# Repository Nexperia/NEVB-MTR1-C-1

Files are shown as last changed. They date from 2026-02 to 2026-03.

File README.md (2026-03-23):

<picture align="center">
  <source media="(prefers-color-scheme: dark)" srcset="https://raw.githubusercontent.com/Nexperia/NEVB-MTR1-C-1/refs/heads/main/images/nexperia_logo_white.svg">
  Nexperia Logo
</picture>

-----------------
# NEVB-MTR1-C-1: Motor Controller Board Hardware Design Files

 

## Introduction

This repository contains the hardware design files for the NEVB-MTR1-C-1 Motor Controller Board, a key component of Nexperia's Motor Evaluation Kit NEVB-MTR1-KIT1. The controller board serves as the central unit for motor control operations, interfacing between the microcontroller (Arduino Leonardo) and the 3-Phase Inverter Board.

The NEVB-MTR1-KIT1 evaluation kit includes:

- **Motor Controller Board (NEVB-MTR1-C-1)**: The central unit for motor control operations (this repository).
- **3-Phase Inverter Board (NEVB-MTR1-I56-1)**: The main powerstage for driving the motor.
- **Leonardo R3 Development Board**: Acts as the core microcontroller platform for the system.
- **3-Phase BLDC Motor with Hall Sensors**: The motor that is directly controlled by the system.
- Additional screws, plugs, and tools necessary for setup and operation.

## Board View

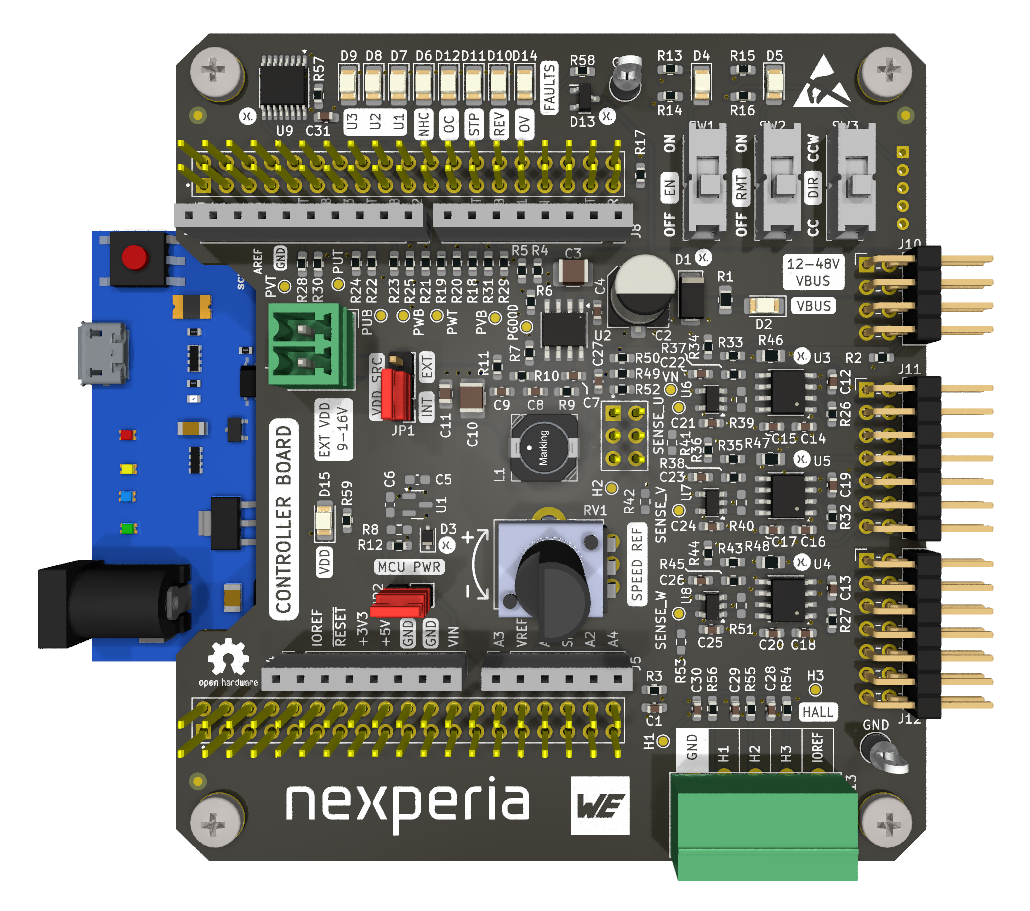
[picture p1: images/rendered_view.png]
Board Render


## Bill of Materials

An interactive Bill of Materials (iBOM) is available online at [https://nexperia.github.io/NEVB-MTR1-C-1/ibom.html](https://nexperia.github.io/NEVB-MTR1-C-1/ibom.html) or locally in the `bom/` directory (`bom/ibom.html`). The iBOM provides an interactive view of component placement, reference designators, and sourcing information. The BOM is also available in CSV format at `bom/nevb_mtr1_c_1.csv`.

## Manufacturing Files

Gerber files for PCB manufacturing are located in the `gerbers/` directory.

## Design Software

This board was designed using [KiCad](https://www.kicad.org/) EDA software (version 9.0 or newer recommended).

To open and edit the design:

1. Install KiCad from [https://www.kicad.org/download/](https://www.kicad.org/download/)
2. Open the project file: `nevb_mtr1_c_1.kicad_pro`

## Related Repositories

- **Firmware**: [NEVC-MTR1-t01](https://github.com/Nexperia/NEVC-MTR1-t01) - Trapezoidal control firmware for the evaluation kit
- **3-Phase Inverter Board Hardware Design Files**: [NEVB-MTR1-I56-1](https://github.com/Nexperia/https://github.com/Nexperia/NEVB-MTR1-I56-1) - Design files for the 3-phase inverter board

## Safety Precautions

When working with these hardware designs, exercise caution with high-voltage components and follow proper ESD, assembly, and testing procedures.

## Contributing

Contributions to improve the hardware design are welcome. To contribute:

- Fork the repository.
- Create a new branch for your feature or fix.
- Commit your changes with clear documentation.
- Push to your branch and submit a pull request.

## License

This project is licensed under the MIT/X Consortium License, a permissive free software license. For more details on the MIT/X Consortium License, please refer to the LICENSE file included in this repository.

## Schematics

The controller board design is organized into hierarchical schematic sheets:

Main Schematic

DC-DC Converter

Microcontroller

User Inputs

Gate Drivers

Back EMF Sense

Fault Reporting

Hardware and Notes

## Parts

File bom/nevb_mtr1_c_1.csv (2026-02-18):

Reference | Value | Datasheet | Footprint | Qty | DNP | Manufacturer | Mfg Part No | Mouser Part No | Farnell Part No | RS Part No
C1 | 22p-10V | https://www.we-online.com/components/products/datasheet/885012006004.pdf | Capacitor_SMD:C_0603_1608Metric_Pad1.08x0.95mm_HandSolder | 1 |  | WURTH ELEKTRONIK | 885012006004 | 710-885012006004 | 2533823 | ~
C2 | 10u-100V | https://www.we-online.com/components/products/datasheet/865060845002.pdf | Capacitor_SMD:CP_Elec_6.3x9.9 | 1 |  | WURTH ELEKTRONIK | 865060845002 | 710-865060845002 | 4061463 | ~
C3 | 2.2u-100V | https://www.we-online.com/components/products/datasheet/885012209071.pdf | Capacitor_SMD:C_1210_3225Metric_Pad1.33x2.70mm_HandSolder | 1 |  | WURTH ELEKTRONIK | 885012209071 | 710-885012209071 | 4061686 | ~
C4 | 0.1u-100V | https://www.we-online.com/components/products/datasheet/885012206120.pdf | Capacitor_SMD:C_0603_1608Metric_Pad1.08x0.95mm_HandSolder | 1 |  | WURTH ELEKTRONIK | 885012206120 | 710-885012206120 | 4061680 | ~
C5 | 1u-25V | https://www.we-online.com/components/products/datasheet/885012206076.pdf | Capacitor_SMD:C_0603_1608Metric_Pad1.08x0.95mm_HandSolder | 1 | DNP | WURTH ELEKTRONIK | 885012206076 | 710-885012206076 | 4261502 | ~
C6 | 1u-10V | https://www.we-online.com/components/products/datasheet/885012206026.pdf | Capacitor_SMD:C_0603_1608Metric_Pad1.08x0.95mm_HandSolder | 1 | DNP | WURTH ELEKTRONIK | 885012206026 | 710-885012206026 | 2534018 | ~
C7 | 2.2n-25V | https://www.we-online.com/components/products/datasheet/885012206061.pdf | Capacitor_SMD:C_0603_1608Metric_Pad1.08x0.95mm_HandSolder | 1 |  | WURTH ELEKTRONIK | 885012206061 | 710-885012206061 | 2534028 | ~
C8 | 47p | https://www.we-online.com/components/products/datasheet/885012006036.pdf | Capacitor_SMD:C_0603_1608Metric_Pad1.08x0.95mm_HandSolder | 1 |  | WURTH ELEKTRONIK | 885012006036 | 710-885012006036 | 2533837 | ~
C9 | 3.3n | https://www.we-online.com/components/products/datasheet/885012206062.pdf | Capacitor_SMD:C_0603_1608Metric_Pad1.08x0.95mm_HandSolder | 1 |  | WURTH ELEKTRONIK | 885012206062 | 710-885012206062 | 2534029 | ~
C10 | 47u-16V | https://www.we-online.com/components/products/datasheet/885012109011.pdf | Capacitor_SMD:C_1210_3225Metric_Pad1.33x2.70mm_HandSolder | 1 |  | WURTH ELEKTRONIK | 885012109011 | 710-885012109011 | 4261498 | ~
C11 | 1u-16V | https://www.we-online.com/components/products/datasheet/885012207051.pdf | Capacitor_SMD:C_0805_2012Metric_Pad1.18x1.45mm_HandSolder | 1 |  | WURTH ELEKTRONIK | 885012207051 | 710-885012207051 | 2534058 | ~
C12,C13,C19 | 220n-25V | https://www.we-online.com/components/products/datasheet/885012206073.pdf | Capacitor_SMD:C_0603_1608Metric_Pad1.08x0.95mm_HandSolder | 3 |  | WURTH ELEKTRONIK | 885012206073 | 710-885012206073 | 2495174 | ~
C14,C16,C18,C31 | 0.1u-25V | https://www.we-online.com/components/products/datasheet/885012206071.pdf | Capacitor_SMD:C_0603_1608Metric_Pad1.08x0.95mm_HandSolder | 4 |  | WURTH ELEKTRONIK | 885012206071 | 710-885012206071 | 2495173 | ~
C15,C17,C20 | 1u-25V | https://www.we-online.com/components/products/datasheet/885012206076.pdf | Capacitor_SMD:C_0603_1608Metric_Pad1.08x0.95mm_HandSolder | 3 |  | WURTH ELEKTRONIK | 885012206076 | 710-885012206076 | 4261502 | ~
C21,C22,C23,C24,C25,C26 | 0.1u-16V | https://www.we-online.com/components/products/datasheet/885012206046.pdf | Capacitor_SMD:C_0603_1608Metric_Pad1.08x0.95mm_HandSolder | 6 |  | WURTH ELEKTRONIK | 885012206046 | 710-885012206046 | 2495170 | ~
C27 | 47n | https://www.we-online.com/components/products/datasheet/885012206044.pdf | Capacitor_SMD:C_0603_1608Metric_Pad1.08x0.95mm_HandSolder | 1 |  | WURTH ELEKTRONIK | 885012206044 | 710-885012206044 | 2534022 | ~
C28,C29,C30 | 10n | https://www.we-online.com/components/products/datasheet/885012206014.pdf | Capacitor_SMD:C_0603_1608Metric_Pad1.08x0.95mm_HandSolder | 3 |  | WURTH ELEKTRONIK | 885012206014 | 710-885012206014 | 2534015 | ~
D1 | PTVS60VP1UTP | https://assets.nexperia.com/documents/data-sheet/PTVSXP1UTP_SER.pdf | Diode_SMD:D_SOD-128 | 1 |  | NEXPERIA | PTVS60VP1UTP,115 | 771-PTVS60VP1UTP,115 | 3940904 | ~
D2,D5,D15 | RMT,VDD,VIN | https://www.we-online.com/components/products/datasheet/150120GS75000.pdf | LED_SMD:LED_1206_3216Metric_Pad1.42x1.75mm_HandSolder | 3 |  | WURTH ELEKTRONIK | 150120GS75000 | 710-150120GS75000 | 2322085 | ~
D3 | PMEG3010CEJ | https://assets.nexperia.com/documents/data-sheet/PMEG3010CEJ-Q.pdf | Diode_SMD:D_SOD-323F | 1 |  | NEXPERIA | PMEG3010CEJ,115 | 771-PMEG3010CEJ-T/R | 1757769 | ~
D4 | EN | https://www.we-online.com/components/products/datasheet/150120AS75000.pdf | LED_SMD:LED_1206_3216Metric_Pad1.42x1.75mm_HandSolder | 1 |  | WURTH ELEKTRONIK | 150120AS75000 | 710-150120AS75000 | 2322083 | ~
D6,D7,D8,D9,D10,D11,D12,D14 | NHC,OC,OV,REV,STP,U1,U2,U3 | https://www.we-online.com/components/products/datasheet/150120RS75000.pdf | LED_SMD:LED_1206_3216Metric_Pad1.42x1.75mm_HandSolder | 8 |  | WURTH ELEKTRONIK | 150120RS75000 | 710-150120RS75000 | 2322086 | ~
D13 | BZX84-C56 | https://assets.nexperia.com/documents/data-sheet/BZX84_SER.pdf | project:D_SOT-23 | 1 |  | NEXPERIA | BZX84-C56,215 | 771-BZX84-C56-T/R | 2575189 | ~
G1,G6 | 2.54mm Jumper | https://cdn.harwin.com/pdfs/M7684-M7687.pdf |  | 2 |  | HARWIN | M7685-05 | 855-M7685-05 | 3218478 | ~
G2,G5,G7,G12 | M3x8mm Screw | https://docs.rs-online.com/c4c2/A700000009608830.pdf |  | 4 |  | RS PRO | 264-6436 | ~ | ~ | 264-6436
G3,G4,G9,G10 | M3x25mm F/F Standoff | https://www.we-online.com/components/products/datasheet/970250321.pdf |  | 4 |  | WURTH ELEKTRONIK | 970250321 | 710-970250321 | 2884579 | ~
G8 | For J2 | https://www.we-online.com/components/products/datasheet/691366110002.pdf |  | 1 |  | WURTH ELEKTRONIK | 691366110002 | 710-691366110002 | 3767193 | ~
G11 | For J12 | https://www.we-online.com/components/products/datasheet/691361100005.pdf |  | 1 |  | WURTH ELEKTRONIK | 691361100005 | 710-691361100005 | 1841352 | ~
J1 | VDD | https://www.we-online.com/components/products/datasheet/691321100002.pdf | Connector_Phoenix_MC:PhoenixContact_MCV_1,5_2-G-3.5_1x02_P3.50mm_Vertical | 1 |  | WURTH ELEKTRONIK | 691321100002 | 710-691321100002 | 1841308 | ~
J2,J9 | Conn_02x19 | https://suddendocs.samtec.com/catalog_english/ssq_th.pdf | Connector_PinSocket_2.54mm:PinSocket_2x19_P2.54mm_Vertical | 2 |  | SAMTEC | SSQ-119-03-T-D | 200-SSQ11903TD | 3701046 | ~
J3 | Inputs | ~ | Connector_PinHeader_2.00mm:PinHeader_1x05_P2.00mm_Vertical | 1 | DNP | ~ | ~ | ~ |  | ~
J4,J8 | IOL,Power | https://suddendocs.samtec.com/catalog_english/ssq_th.pdf | Connector_PinSocket_2.54mm:PinSocket_1x08_P2.54mm_Vertical | 2 |  | SAMTEC | SSQ-108-03-T-S | 200-SSQ10803TS | 3550867 | ~
J5 | AO | https://suddendocs.samtec.com/catalog_english/ssq_th.pdf | Connector_PinSocket_2.54mm:PinSocket_1x06_P2.54mm_Vertical | 1 |  | SAMTEC | SSQ-106-03-T-S | 200-SSQ10603TS | 3550863 | ~
J6 | ICSP | https://suddendocs.samtec.com/catalog_english/ssq_th.pdf | Connector_PinSocket_2.54mm:PinSocket_2x03_P2.54mm_Vertical | 1 |  | SAMTEC | SSQ-103-03-T-D | 200-SSQ10303TD | 3550857 | ~
J7 | IOH | https://suddendocs.samtec.com/catalog_english/ssq_th.pdf | Connector_PinSocket_2.54mm:PinSocket_1x10_P2.54mm_Vertical | 1 |  | SAMTEC | SSQ-110-03-T-S | 200-SSQ11003TS | 3550873 | ~
J10 | VIN | https://www.we-online.com/components/products/datasheet/61300821021.pdf | Connector_PinHeader_2.54mm:PinHeader_2x04_P2.54mm_Horizontal | 1 |  | WURTH ELEKTRONIK | 61300821021 | 710-61300821021 | 2356196 | ~
J11,J12 | Signals1,Signals2 | https://www.we-online.com/components/products/datasheet/61301421021.pdf | Connector_PinHeader_2.54mm:PinHeader_2x07_P2.54mm_Horizontal | 2 |  | WURTH ELEKTRONIK | 61301421021 | 710-61301421021 | 2356198 | ~
J13 | HALL | https://www.we-online.com/components/products/datasheet/691322110005.pdf | Connector_Phoenix_MC:PhoenixContact_MC_1,5_5-G-3.5_1x05_P3.50mm_Horizontal | 1 |  | WURTH ELEKTRONIK | 691322110005 | 710-691322110005 | 1841318 | ~
JP1 | VDD | https://www.we-online.com/components/products/datasheet/61300311121.pdf | Connector_PinHeader_2.54mm:PinHeader_1x03_P2.54mm_Vertical | 1 |  | WURTH ELEKTRONIK | 61300311121 | 710-61300311121 | 2356154 | ~
JP2 | PWR | https://www.we-online.com/components/products/datasheet/61300211121.pdf | Connector_PinHeader_2.54mm:PinHeader_1x02_P2.54mm_Vertical | 1 |  | WURTH ELEKTRONIK | 61300211121 | 710-61300211121 | 2356153 | ~
L1 | 68u | https://www.we-online.com/components/products/datasheet/7447773680.pdf | project:L_WE_PD_7345P | 1 |  | WURTH ELEKTRONIK | 7447773680 | 710-7447773680 | 3221536 | ~
R1 | 100K | http://www.kamaya.co.jp/upload/products_pdf/kamaya_products(RMC1-32,RMC1-20,RMC1-16S,RMC1-16,RMC1-10,RMC1-8,RMC1-4,RMC1-2,RMC1)_english_20240824_132441.pdf | Resistor_SMD:R_0805_2012Metric_Pad1.20x1.40mm_HandSolder | 1 |  | KAMAYA | RMC1/10K1003FTP | 791-RMC1/10K1003FTP | ~ | ~
R2,R4,R6,R7 | 100K | https://www.yageo.com/upload/media/product/app/datasheet/rchip/pyu-rt_1-to-0.01_rohs_l.pdf | Resistor_SMD:R_0603_1608Metric_Pad0.98x0.95mm_HandSolder | 4 |  | YAGEO | RT0603FRE07100KL | 603-RT0603FRE07100KL | 1500586 | ~
R3 | 6.2K | https://www.yageo.com/upload/media/product/products/datasheet/rchip/PYu-RC_Group_51_RoHS_L_12.pdf | Resistor_SMD:R_0603_1608Metric_Pad0.98x0.95mm_HandSolder | 1 |  | YAGEO | RC0603FR-076K2L | 603-RC0603FR-076K2L | 3495902 | ~
R5 | 15K | https://www.bourns.com/docs/product-datasheets/cr.pdf | Resistor_SMD:R_0603_1608Metric_Pad0.98x0.95mm_HandSolder | 1 |  | BOURNS | CR0603-FX-1502ELF | 652-CR0603FX-1502ELF | 2333567 | ~
R8,R41,R42,R53 | 0 | https://www.yageo.com/upload/media/product/products/datasheet/rchip/PYu-RC_Group_51_RoHS_L_12.pdf | Resistor_SMD:R_0603_1608Metric_Pad0.98x0.95mm_HandSolder | 4 | DNP | YAGEO | RC0603FR-070RL | 603-RC0603FR-070RL | 2309106 | ~
R9,R10 | 453K | https://www.yageo.com/upload/media/product/products/datasheet/rchip/PYu-RC_Group_51_RoHS_L_12.pdf | Resistor_SMD:R_0603_1608Metric_Pad0.98x0.95mm_HandSolder | 2 |  | YAGEO | RC0603FR-07453KL | 603-RC0603FR-07453KL | 3950841 | ~
R11 | 49.9K | https://www.bourns.com/docs/product-datasheets/cr.pdf?sfvrsn=574d41f6_14 | Resistor_SMD:R_0603_1608Metric_Pad0.98x0.95mm_HandSolder | 1 |  | BOURNS | CR0603-FX-4992ELF | 652-CR0603FX-4992ELF | CR0603-FX-4992ELF | ~
R12,R26,R27,R32,R37,R38,R45,R52 | 0 | https://www.yageo.com/upload/media/product/products/datasheet/rchip/PYu-RC_Group_51_RoHS_L_12.pdf | Resistor_SMD:R_0603_1608Metric_Pad0.98x0.95mm_HandSolder | 8 |  | YAGEO | RC0603FR-070RL | 603-RC0603FR-070RL | 2309106 | ~
R13,R18,R19,R22,R23,R28,R29 | 1K | http://www.kamaya.co.jp/upload/products_pdf/kamaya_products(RMC1-32,RMC1-20,RMC1-16S,RMC1-16,RMC1-10,RMC1-8,RMC1-4,RMC1-2,RMC1)_english_20240824_132441.pdf | Resistor_SMD:R_0603_1608Metric_Pad0.98x0.95mm_HandSolder | 7 |  | KAMAYA | RMC1/16-102JTP | 791-RMC1/16-102JTP | ~ | ~
R14,R15,R16,R17,R20,R21,R24,R25,R30,R31,R54,R55,R56 | 10K | http://www.kamaya.co.jp/upload/products_pdf/kamaya_products(RMC1-32,RMC1-20,RMC1-16S,RMC1-16,RMC1-10,RMC1-8,RMC1-4,RMC1-2,RMC1)_english_20240824_132441.pdf | Resistor_SMD:R_0603_1608Metric_Pad0.98x0.95mm_HandSolder | 13 |  | KAMAYA | RMC1/16-103JTP | 791-RMC1/16103JTP | ~ | ~
R33,R35,R43,R49 | 110K | https://www.yageo.com/upload/media/product/productsearch/datasheet/rchip/PYu-AC_51_RoHS_L_10.pdf | Resistor_SMD:R_0603_1608Metric_Pad0.98x0.95mm_HandSolder | 4 |  | YAGEO | AC0603FR-07110KL | 603-AC0603FR-07110KL | 3952185 | ~
R34,R36,R44,R50 | 4.99K | https://industrial.panasonic.com/cdbs/www-data/pdf/RDA0000/AOA0000C304.pdf | Resistor_SMD:R_0603_1608Metric_Pad0.98x0.95mm_HandSolder | 4 |  | PANASONIC | ERJ-3EKF4991V | 667-ERJ-3EKF4991V | 2692541 | ~
R39,R40,R51 | TBD | ~ | Resistor_SMD:R_0603_1608Metric_Pad0.98x0.95mm_HandSolder | 3 | DNP | ~ | ~ | ~ | ~ | ~
R46,R47,R48 | 1K | https://www.yageo.com/upload/media/product/products/datasheet/rchip/PYu-RC_Group_51_RoHS_L_12.pdf | Resistor_SMD:R_0805_2012Metric_Pad1.20x1.40mm_HandSolder | 3 |  | YAGEO | RC0805FR-101KL | 603-RC0805FR-101KL | 9237496 | ~
R57 | 750 | http://www.kamaya.co.jp/upload/products_pdf/kamaya_products(RMC1-32,RMC1-20,RMC1-16S,RMC1-16,RMC1-10,RMC1-8,RMC1-4,RMC1-2,RMC1)_english_20240824_132441.pdf | Resistor_SMD:R_0603_1608Metric_Pad0.98x0.95mm_HandSolder | 1 |  | KAMAYA | RMC16K751FTP | 791-RMC16K751FTP | ~ | ~
R58 | 220 | https://www.yageo.com/upload/media/product/products/datasheet/rchip/PYu-RC_Group_51_RoHS_L_12.pdf | Resistor_SMD:R_0603_1608Metric_Pad0.98x0.95mm_HandSolder | 1 |  | YAGEO | RC0603JR-07220RL | 603-RC0603JR-07220RL | 9233296 | ~
R59 | 27K | https://bourns.com/docs/product-datasheets/cr.pdf | Resistor_SMD:R_0603_1608Metric_Pad0.98x0.95mm_HandSolder | 1 |  | BOURNS | CR0603-FX-2702ELF | 652-CR0603FX-2702ELF | 2908288 | ~
RV1 | 10K | https://www.bourns.com/pdfs/PTV09.pdf | Potentiometer_THT:Potentiometer_Bourns_PTV09A-1_Single_Vertical | 1 |  | BOURNS | PTV09A-4225U-B103 | 652-PTV09A-4225UB103 | 2663537 | ~
SW1,SW2,SW3 | DIR,EN,RMT | https://configured-product-images.s3.amazonaws.com/2D/specs/EG1218.pdf | project:EG1218 | 3 |  | E-SWITCH | EG1218 | 612-EG1218 | 2787232 | ~
TP8,TP9 | GND | https://www.keyelco.com/product-pdf.cfm?p=14635 | project:TestPoint_THTPad_D3.0mm_Drill1.5mm | 2 |  | KEYSTONE ELECTRONICS | 5288 | 534-5288 | ~ | ~
U1 | MCP1754S | http://ww1.microchip.com/downloads/en/DeviceDoc/20002276C.pdf | Package_TO_SOT_SMD:SOT-23 | 1 | DNP | MICROCHIP TECHNOLOGY | MCP1754ST-5002E/CB | 579-MCP1754T-5002ECB | 2065849 | ~
U2 | LM5164DDA | https://www.ti.com/lit/ds/symlink/lm5164.pdf | project:HSOP-8-1EP_3.9x4.9mm_P1.27mm_EP2.41x3.1mm_ThermalVias | 1 |  | TEXAS INSTRUMENTS | LM5164DDAR | 595-LM5164DDAR | ~ | ~
U3,U4,U5 | NGD4300D | https://assets.nexperia.com/documents/data-sheet/NGD4300.pdf | Package_SO:SO-8_3.9x4.9mm_P1.27mm | 3 |  | NEXPERIA | NGD4300DJ | 771-NGD4300DJ | 4574123 | ~
U6,U7,U8 | MCP6561 | https://ww1.microchip.com/downloads/en/DeviceDoc/MCP6561-1R-1U-2-4-1.8V-Low-Power-Push-Pull-Output-Comparator-DS20002139E.pdf | Package_TO_SOT_SMD:SOT-23-5 | 3 |  | MICROCHIP TECHNOLOGY | MCP6561T-E/OT | 579-MCP6561T-E/OT | 1715874 | ~
U9 | CBT3251 | https://assets.nexperia.com/documents/data-sheet/CBT3251.pdf | Package_SO:TSSOP-16_4.4x5mm_P0.65mm | 1 |  | NEXPERIA | CBT3251PW,118 | 771-CBT3251PW118 | 2445292 | ~

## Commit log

2026-02-18 feat: public release of rev 1 design files
    [back_emf_sense.kicad_sch, dc_dc_converter.kicad_sch, fault_reporting.kicad_sch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]
2026-02-18 chore: update README and add board view
